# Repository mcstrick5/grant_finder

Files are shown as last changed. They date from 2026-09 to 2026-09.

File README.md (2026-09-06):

# Slide-Out Pan Commode - Manufacturer Brief (Rev A, concept design)

## What it is
A standard folding aluminium bedside commode (1" tube frame, telescoping legs, round 440 mm PP seat/lid, padded backrest, armrests)
fitted with a **side slide-out pan module**. The pan rides on two full-extension ball-bearing drawer
slides mounted under the seat on the existing front and rear cross bars. A caregiver pulls the handle,
the pan slides ~20" (508 mm) out to the side **while the user remains seated**, is lifted straight out
of its carrier by its two end grips, emptied, dropped back in and pushed home where a catch holds it.

## How it works (see Sheet 1 and renders)
1. Two 20" (508 mm) full-extension slides, one clamped under the front cross bar and one under the rear
   cross bar, running side-to-side. Six rubber-lined tube clamps (SP-04) - no welding or drilling of the
   chair frame; the module is a retrofit kit.
2. A carrier plate (SP-01, 400 x 379 mm) is bolted to the moving members of both slides. It has a
   320 mm dia round cutout, concentric with the seat aperture.
3. The round pan (SP-02, 310 mm rim dia) hangs by its 15 mm flange in the cutout, directly under the seat aperture. Its rim top
   sits 22 mm below the seat underside. Pan bottom is 276 mm above the floor - clears the lower side brace.
4. At full extension the pan is entirely outside the leg line (63 mm clearance past the inner face of the
   leg) so it lifts vertically out. A snap-on splash lid (SP-03) is fitted before carrying.
5. Padded backrest (SP-05, 460 x 200 x 45 mm foam/vinyl) straps to the FRONT face of the rear back-bar so a
   user leaning back contacts padding, never the tube.
6. A magnetic catch / spring detent holds the carrier in the closed position; bump stops at full travel.

## Key dimensions
| Item | mm | in |
|---|---|---|
| Overall width / depth | 585 x 455 | 23.0 x 17.9 |
| Seat height (nominal, adjustable) | 470 (420-570) | 18.5 (16.5-22.5) |
| Slide travel | 508 | 20.0 |
| Carrier plate (round cutout 320 dia) | 400 x 379 x 6 | 15.75 x 14.93 x 0.24 |
| Pan rim dia / flange O/A dia / base dia | 310 / 340 / 250 | 12.2 / 13.4 / 9.8 |
| Pan depth | 152 | 6.0 |
| Pan capacity (working / brim) | 6.7 L / 9.3 L | 7 qt / 9.8 qt |
| Design load | 136 kg seated, 15 kg in pan | 300 lb / 33 lb |

## Files
| File | Purpose |
|---|---|
| `commode_slide_pan_closed.step` / `.stl` | Full 3D assembly, pan closed (STEP opens in AutoCAD, SolidWorks, Fusion, FreeCAD) |
| `commode_slide_pan_extended.step` / `.stl` | Full 3D assembly, pan at full extension |
| `part_carrier.step/.stl`, `part_pan.step/.stl`, `part_slides.step/.stl`, `part_backrest.step/.stl` | Individual new parts |
| `sheet1_general_assembly.pdf/.dxf` | GA drawing: front, side, top views, overall dims, notes |
| `sheet2_carrier_plate.pdf/.dxf` | Carrier plate detail + section |
| `sheet3_pan.pdf/.dxf` | Pan detail + section, draft, fill line |
| `sheet4_bracket_bom.pdf/.dxf` | Clamp bracket detail + full Bill of Materials |
| `render_01..06.png` | Shaded renders for quoting / marketing |
| `model.py`, `drawings.py`, `render.py` | Parametric source (CadQuery) - change any dimension and regenerate |

## Questions for the manufacturer / decisions still open
- Material choice for carrier (HDPE vs 304 SS) and pan (moulded PP vs drawn SS) - tooling cost vs volume.
- Handedness: RH shown (slides out to caregiver's right when facing user). Offer LH mirror?
- Slide spec: confirm 100 lb/pair, corrosion-resistant (stainless or zinc + sealed bearings) and washable.
- Whether the base chair is bought-in (retrofit kit) or the manufacturer supplies the whole chair.
- Optional: splash lid that closes automatically as the pan slides out (hinged flap on carrier) - not in Rev A.

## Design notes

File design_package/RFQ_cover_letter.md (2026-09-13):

# REQUEST FOR QUOTE - Rear Slide-Out Pan Bedside Commode (Rev B)

## Date

________________

## Project

Retrofit module for a standard folding aluminium bedside commode that lets a caregiver empty the waste pan
while the user remains seated. The round pan slides 20" (508 mm) straight out the BACK of the chair on two
ball-bearing drawer slides, lifts out for emptying, and slides back to a latched position under the seat.

## Scope of quote

Please quote the following, priced separately:
  A. Prototype: 1 complete working unit (module fitted to a base chair) for fit and function testing.
  B. Pilot run: 10 units.
  C. Production: 100 and 500 units (unit price, tooling, lead time).
For each, state whether you supply the base chair or fit the module to a chair we supply.

## Parts to be made / sourced (see Sheet 4 BOM for full list)
```
  SP-01  Carrier plate 375 x 400 x 6 mm, 320 mm round cutout, side flanges, rear D-handle  (Sheet 2)
  SP-02  Round pan, 310 mm rim / 340 mm flange / 250 mm base, 152 mm deep, 7 qt working  (Sheet 3)
  SP-03  Snap-on splash lid for pan
  SP-04  Tube clamp bracket, 1" saddle with foot, rubber-lined, qty 4  (Sheet 4)
  SP-05  Padded backrest 460 x 200 x 45 mm, mounts in FRONT of the rear bar
  SP-06  Angle rail 40 x 40 x 3 mm x 508 mm, 6061-T6, qty 2  (Sheet 4)
  Bought-in: 2x 20" full-extension slides (100 lb/pair, corrosion resistant), D-handle, magnetic catch,
  bump stops, stainless fasteners.
```

## Key requirements
```
  - Retrofit: clamps to the existing frame, no welding or drilling of the chair.
  - Pan and carrier concentric with the 440 mm round seat; pan must lift freely out of the carrier at full extension.
  - Design load 300 lb (136 kg) seated user; 15 kg in pan at full extension; no tipping with pan extended.
  - Pan, lid and carrier smooth, non-porous, dishwasher/disinfectant safe (PP or 304 SS).
  - Slides and hardware stainless or zinc-plated with sealed bearings; washable.
  - Tolerances per drawings (+/-1.0 mm untoleranced); all edges deburred.
```

## Supplier to confirm / advise
```
  1. Material recommendation for carrier (HDPE vs 304 SS) and pan (moulded PP vs drawn SS) at each volume.
  2. Engineering review of slide/rail loading and tip stability with the pan extended; propose changes if needed.
  3. Whether the design fits your standard commode frame, or dimensions that must change.
  4. Lead time for prototype, pilot and production; tooling costs and ownership; MOQ.
```

## US market / regulatory requirements (product ships to the United States)
```
  - FDA: commode is a Class I medical device (21 CFR 890.3100/890.3110, 510(k)-exempt). Manufacturer must hold
    FDA Establishment Registration and Device Listing and follow 21 CFR 820 QMS (or ISO 13485). Provide evidence.
  - Testing: static load and stability per ISO 17966 (assistive products for personal hygiene) and/or RESNA;
    supply test reports for 300 lb (136 kg) rated user load with pan extended.
  - Materials: skin-contact parts biocompatible (ISO 10993-5/-10); pan/lid plastics food-grade PP. Vinyl, foam and
    plastics to meet California Prop 65 and CPSIA/16 CFR limits for lead, cadmium and phthalates; RoHS declaration.
  - Corrosion: salt-spray / cleaning-agent resistance test on slides, rails, clamps and fasteners (e.g. ASTM B117).
  - Labeling: permanent label with model, rated load, manufacturer, country of origin (19 CFR 134 'Made in China'),
    English instructions for use and cleaning; UDI/labeling per 21 CFR 801 as applicable.
  - Quality: ISO 9001 certificate; pre-shipment inspection (AQL) report; packaging drop test (ISTA/ASTM D4169).
  - Supplier to state the HTS code and confirm any US import tariff applicable to their quote.
```

## Files provided
```
  README_manufacturer_brief.md (start here)  |  sheet1-4 PDF + DXF drawings and BOM
  commode_slide_pan_closed / _extended .STEP + .STL (full assembly)  |  part_*.step (individual parts)
  render_01-06.png (how it works)  |  model.py / drawings.py / render.py (parametric source)
```

## Note

This is a concept design based on standard commode dimensions and has not been physically tested.
Fit to the actual base chair and all structural/safety validation are to be performed by the supplier.

Please reply with your quotation and any design comments. Thank you.

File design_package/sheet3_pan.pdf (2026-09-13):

## TOP VIEW

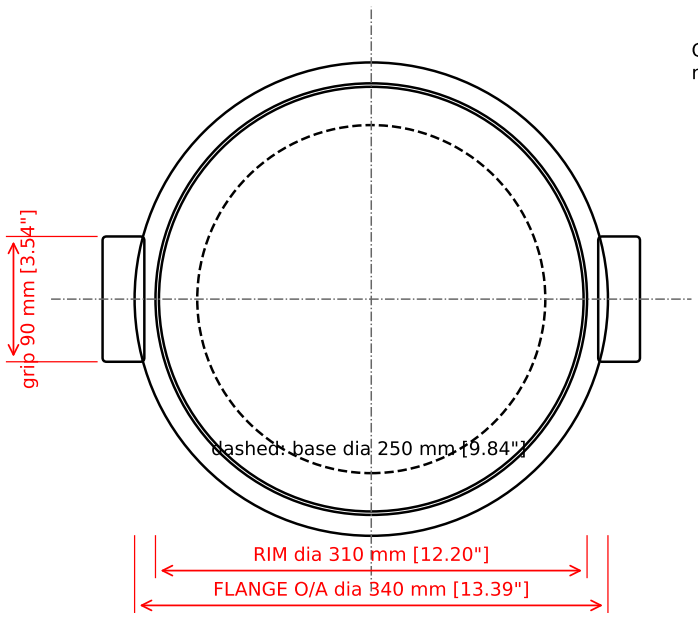
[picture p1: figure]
FLANGE O/A dia 340 mm [13.39"]; RIM dia 310; grip 90 mm [3.54"]; dashed: base dia

Concentric with 440 mm round seat; rim surrounds 300 x 220 seat aperture.

## SECTION B-B (through centre)

MAX FILL line (moulded), 7 qt / 6.7 L

DEPTH 152 mm [6.00"]

BASE dia 250 mm [9.84"]

FLANGE 15 mm [0.59"]

NOTES
0. Round (revolved) pan. Draft angle 11.3 deg. Wall 2.5 mm nominal. Base corner R15 inside.
1. Capacity: ~9.3 L brim-full; 7 qt (6.7 L) working capacity at moulded MAX FILL line 115 mm above base. Concentric with the 440 mm round seat and its 300 x 220 aperture (pan rim 310 dia fully surrounds aperture).
2. Flange rests on carrier plate cutout (Sheet 2). Two moulded end grips for lift-out.
3. Supply with snap-on splash lid (P/N SP-03, same rim profile) - lid fitted once pan is extended before carrying.
4. Material: polypropylene copolymer, min. 2.5 mm wall, autoclavable / dishwasher-safe. Alt: 0.8 mm 304 SS deep-drawn, polished.
5. Tolerance +/-1.0 mm; rim must pass freely through carrier cutout (5 mm radial clearance); flange OD 340 clears carrier side flanges (369 inside).

# SHEET 3 - REMOVABLE ROUND PAN (P/N SP-02) moulded PP or 0.8 mm 304 SS drawn (units mm [in])

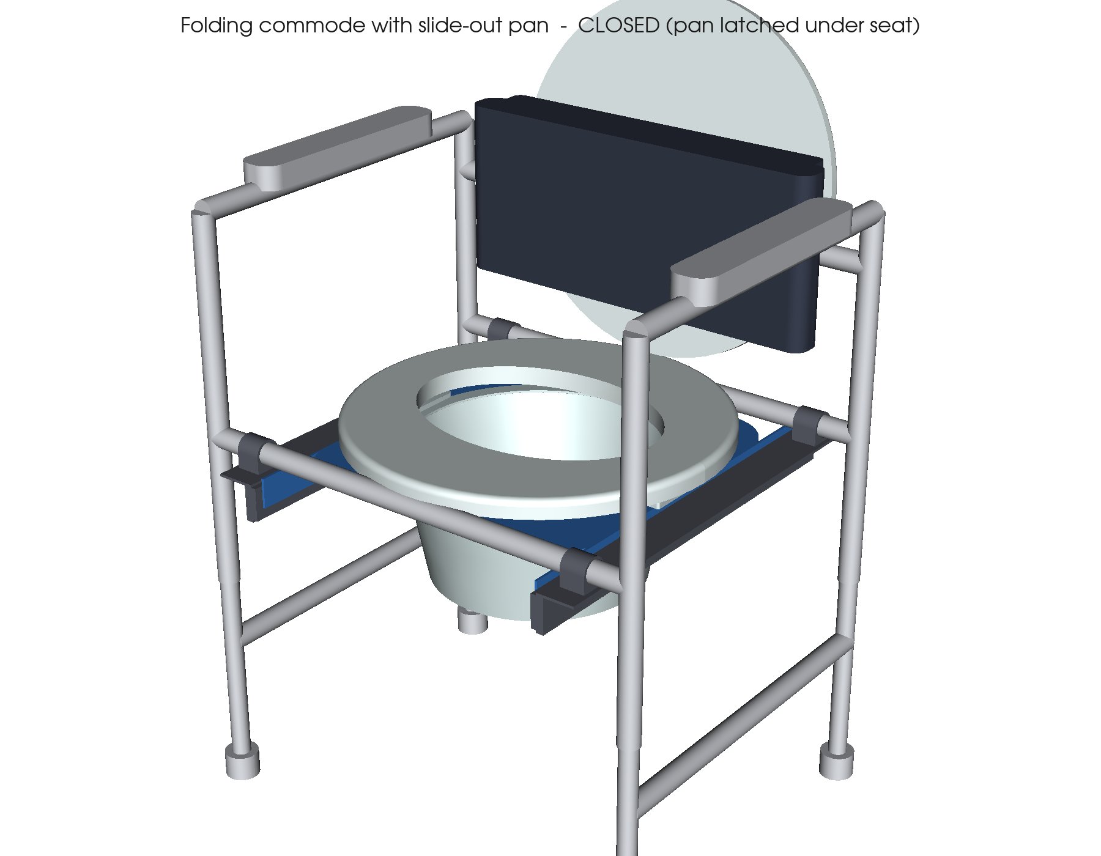
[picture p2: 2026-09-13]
design_package/render_01_closed_iso.png

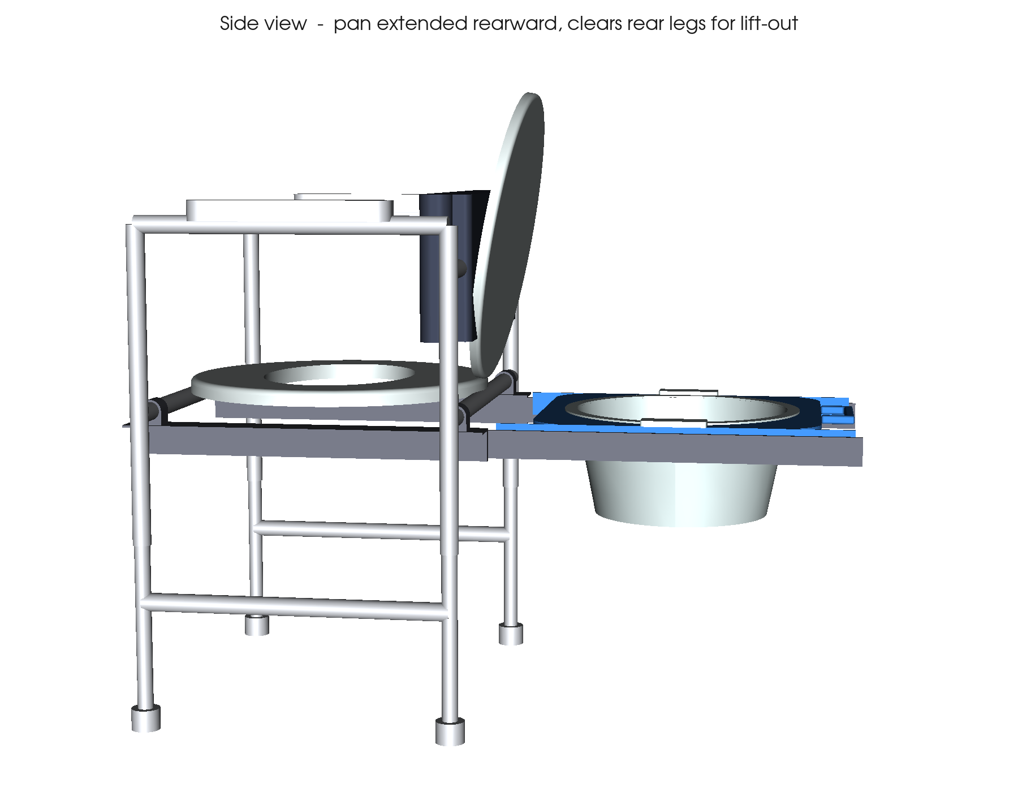
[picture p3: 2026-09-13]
design_package/render_03_extended_side.png

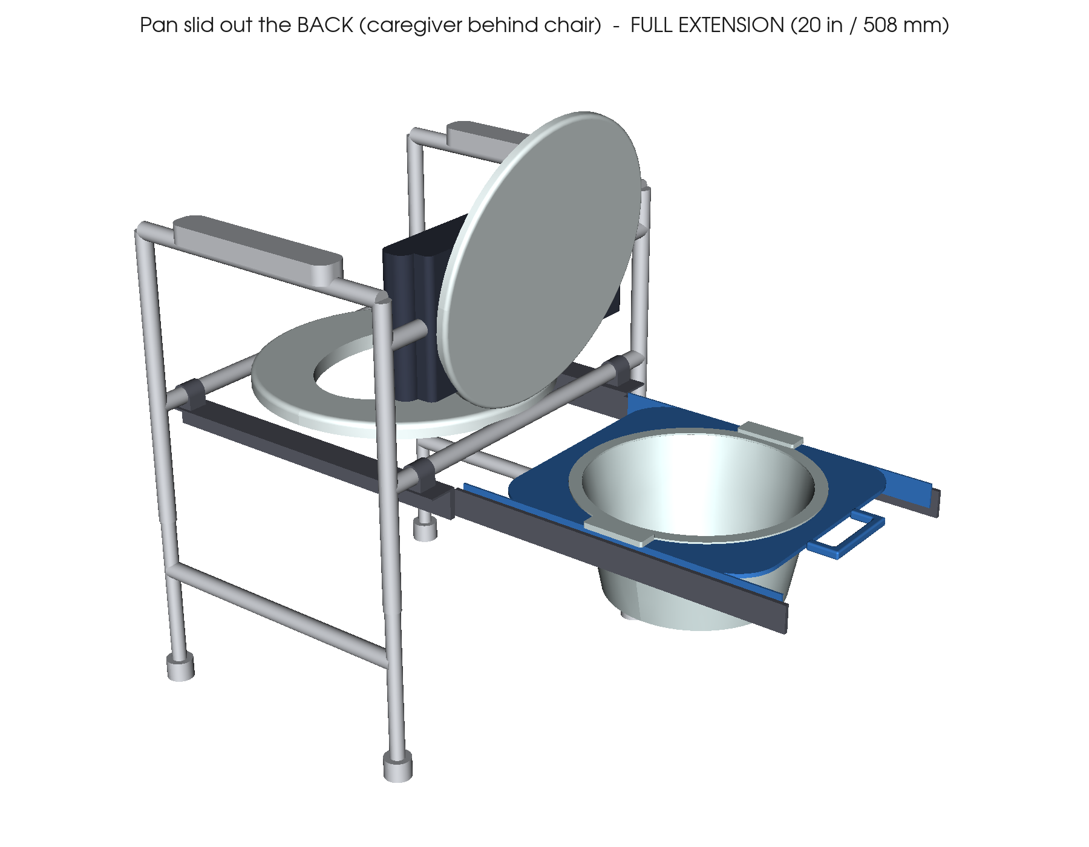
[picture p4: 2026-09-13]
design_package/render_02_extended_iso.png

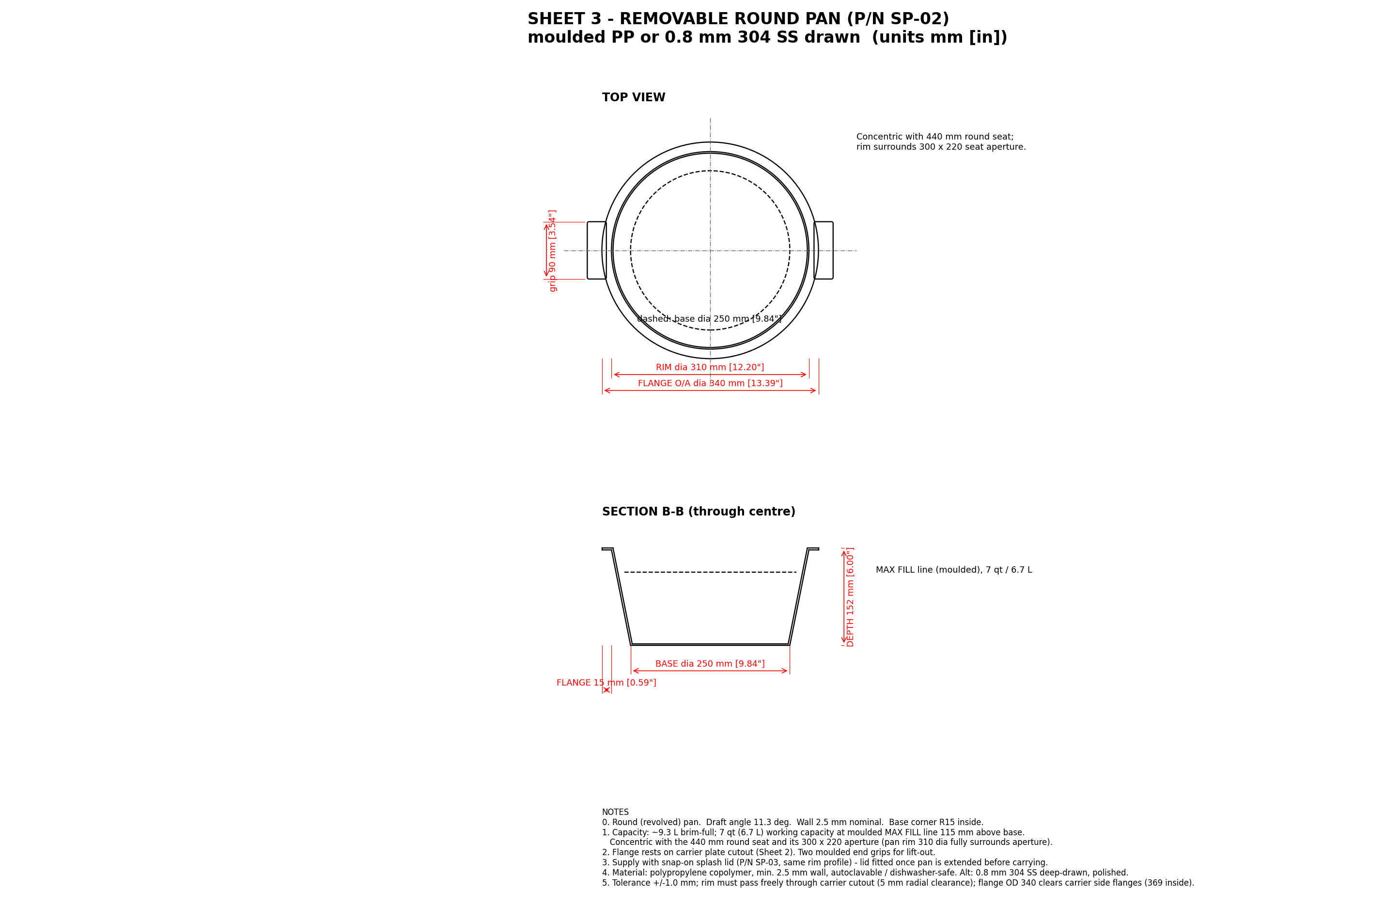
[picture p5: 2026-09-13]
design_package/sheet3_pan.png

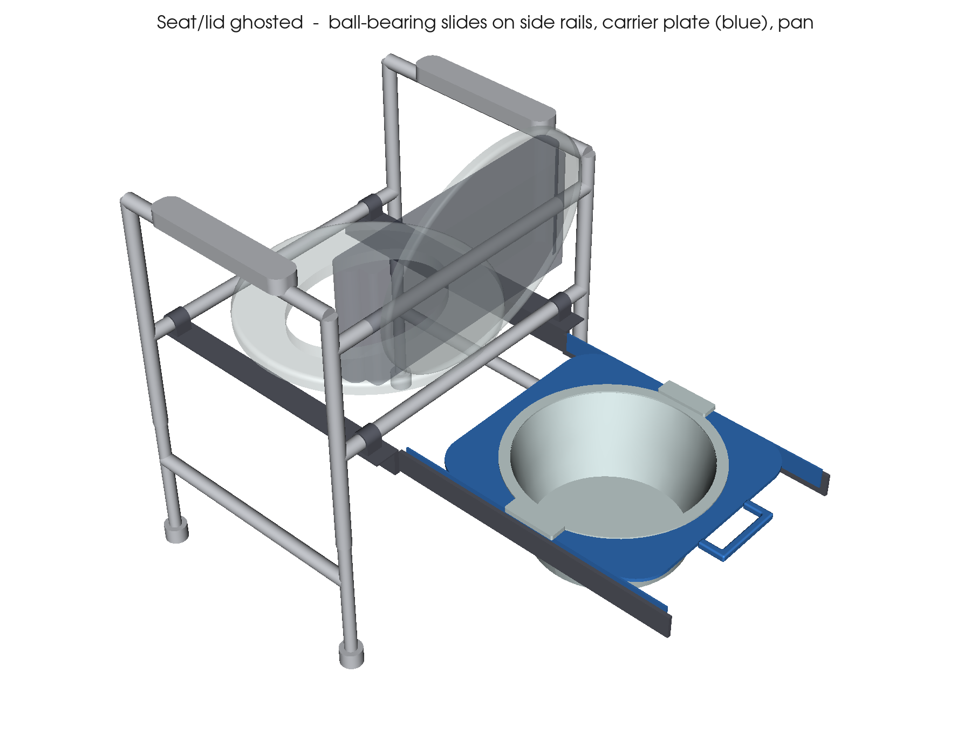
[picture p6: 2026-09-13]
design_package/render_04_extended_seat_ghosted.png

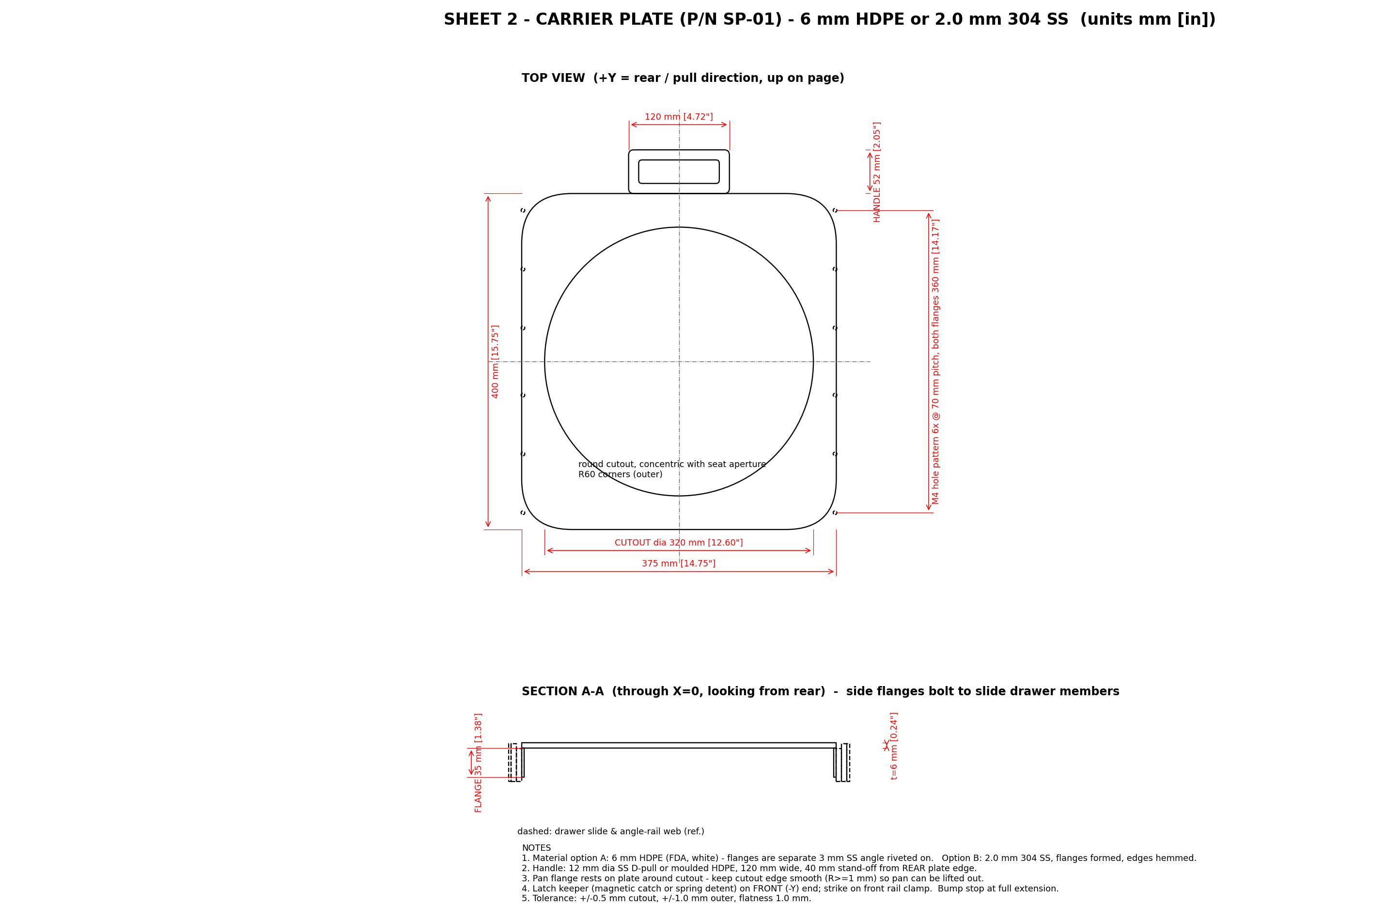
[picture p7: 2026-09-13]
design_package/sheet2_carrier_plate.png

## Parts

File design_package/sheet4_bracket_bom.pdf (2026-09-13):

## CLAMP BRACKET - END VIEW

(2-piece saddle + foot, 30 mm long,

## seen along cross bar)

O/D 31 mm [1.24"]

FOOT 20 mm [0.79"] (bar C/L to rail top) bore 25 mm [1.00"] (1 in tube)

Material: 6061-T6 aluminium or glass-filled nylon. 2x M5 clamp screws (split line), 2x M4 screws down into angle-rail top leg. Rubber liner 1 mm inside bore
to protect powder-coat & prevent slip.
Qty 4 (front & rear cross bar, at X = +/-220 mm).
RAIL SP-06: 40x40x3 6061-T6 angle, 508 mm long, web faces inboard; slide cabinet member bolts to web (4x M4), qty 2.
ITEM | P/N | DESCRIPTION | MATERIAL | QTY
1 | BASE | Folding commode chair, 1" alu frame, seat, lid, arms (existing / purchased) | Aluminium / PP | 1
2 | SLD-20 | Full-extension ball-bearing drawer slide, 20" (508 mm), 45 mm, 100 lb/pair, detent | Zinc-plated or SS | 2
3 | SP-01 | Carrier plate with formed flanges & cutout (Sheet 2) | 6 mm HDPE or 2 mm 304 SS | 1
4 | SP-02 | Removable pan, flanged rim, end grips (Sheet 3) | PP copolymer / 304 SS | 1
5 | SP-03 | Snap-on splash lid for SP-02 | PP copolymer | 1
6 | SP-04 | Tube clamp bracket, 1" saddle with foot (this sheet) | 6061-T6 or GF nylon | 4
6a | SP-06 | Angle rail 40x40x3 x 508 mm, drilled for slide + 2 clamps (this sheet) | 6061-T6 aluminium | 2
7 | HDL-120 | D-pull handle 120 mm, 12 mm dia | 304 SS | 1
8 | LTCH | Magnetic catch 5 kg (or spring ball detent) + strike | SS / nylon | 1
9 | HW | M4x10 SS button-head screws + nyloc (slide to carrier flange) | A2 SS | 12
10 | HW | M5x20 SS screws + nyloc (clamp halves) | A2 SS | 8
11 | HW | M4x8 SS screws (clamp foot to rail; slide cabinet member to rail web) | A2 SS | 16
12 | STOP | Rubber bump stop 15 mm (full-extension stop on slide) | EPDM | 2
13 | SP-05 | Backrest pad 460x200x45, wraps FRONT of back-bar, rear shell w/ 2 hook-&-loop straps | PU foam / vinyl, PP shell | 1

## BILL OF MATERIALS - slide-out pan module

GENERAL
- Dimensions in mm [inches]. Untoleranced +/-1.0 mm. Break all edges 0.5 mm.
- Frame contact parts must not damage powder-coat: use rubber-lined clamps.
- Slide rails to be mounted parallel within 0.5 mm over 508 mm; check free travel with 20 kg in pan.
- Design load: 136 kg (300 lb) seated user on base chair; 15 kg in pan on slides at full extension.
- Finish: pan & carrier smooth, non-porous, cleanable with hospital disinfectants.
- Pan extends to the REAR of the chair (caregiver behind user); no left/right handedness.

# SHEET 4 - TUBE CLAMP BRACKET (P/N SP-04) & BILL OF MATERIALS (units mm [in])

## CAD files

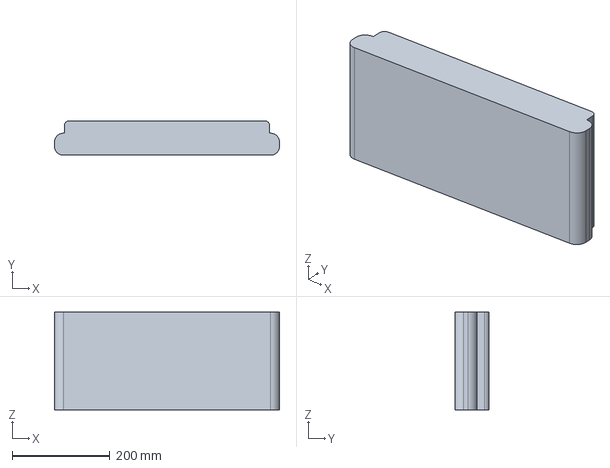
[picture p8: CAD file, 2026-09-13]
design_package/part_backrest.step
460.0 x 70.4 x 200.0 mm

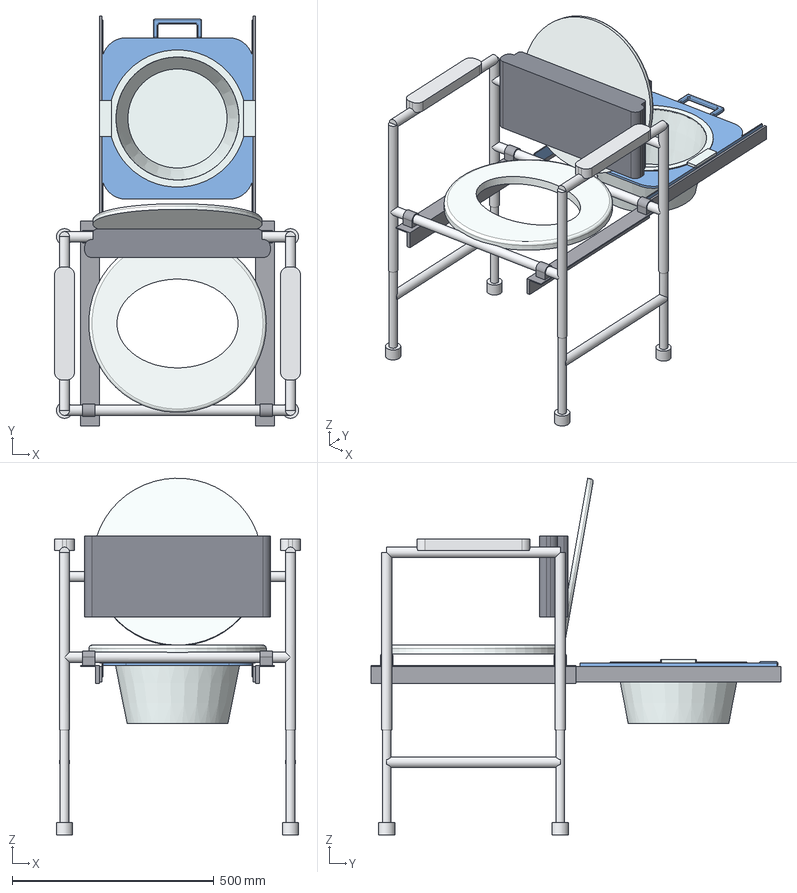
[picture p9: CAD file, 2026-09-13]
design_package/commode_slide_pan_extended.step
610.0 x 1016.0 x 883.5 mm
frame
seat
lid
backrest
slides
carrier
pan

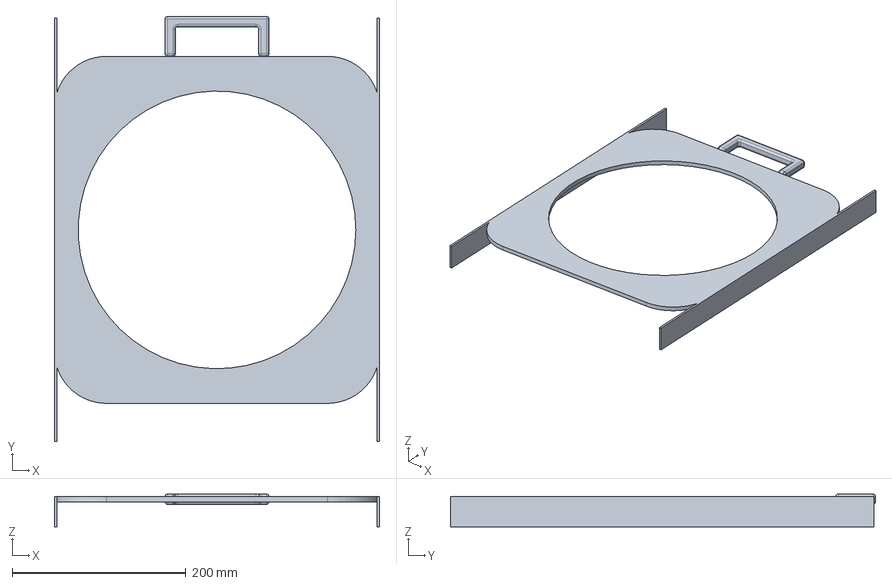
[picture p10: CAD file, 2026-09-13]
design_package/part_carrier.step
374.6 x 490.0 x 38.0 mm

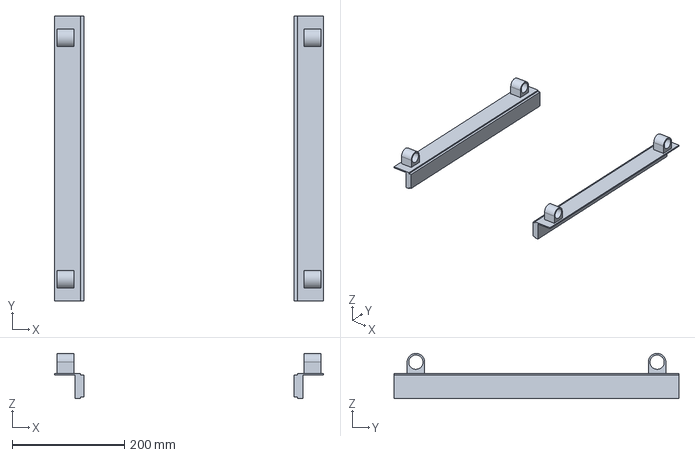
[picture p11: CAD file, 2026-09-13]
design_package/part_slides.step
480.0 x 508.0 x 80.7 mm

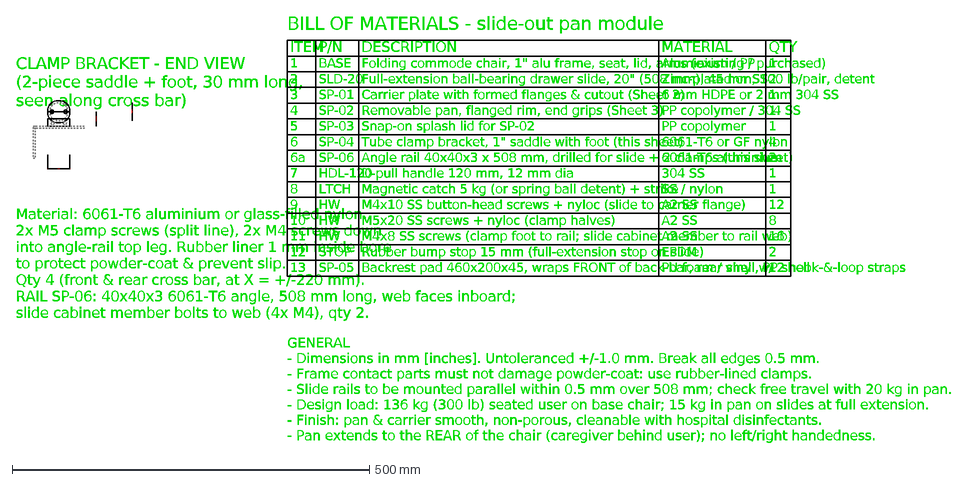
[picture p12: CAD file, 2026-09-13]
design_package/sheet4_bracket_bom.dxf
CLAMP BRACKET - END VIEW
(2-piece saddle + foot, 30 mm long,
seen along cross bar)
O/D 31 mm [1.24"]
FOOT 20 mm [0.79"] (bar C/L to rail top)
bore 25 mm [1.00"] (1 in tube)
Material: 6061-T6 aluminium or glass-filled nylon.
2x M5 clamp screws (split line), 2x M4 screws down
into angle-rail top leg. Rubber liner 1 mm inside bore
to protect powder-coat & prevent slip.
Qty 4 (front & rear cross bar, at X = +/-220 mm).
RAIL SP-06: 40x40x3 6061-T6 angle, 508 mm long, web faces inboard;
slide cabinet member bolts to web (4x M4), qty 2.
ITEM
P/N
DESCRIPTION
MATERIAL
QTY
1
BASE
Folding commode chair, 1" alu frame, seat, lid, arms (existing / purchased)
Aluminium / PP
2
SLD-20
Full-extension ball-bearing drawer slide, 20" (508 mm), 45 mm, 100 lb/pair, detent
Zinc-plated or SS
3
SP-01
Carrier plate with formed flanges & cutout (Sheet 2)
6 mm HDPE or 2 mm 304 SS
4
SP-02
Removable pan, flanged rim, end grips (Sheet 3)
PP copolymer / 304 SS
5
SP-03
Snap-on splash lid for SP-02
PP copolymer
6
SP-04
Tube clamp bracket, 1" saddle with foot (this sheet)
6061-T6 or GF nylon
6a
SP-06
Angle rail 40x40x3 x 508 mm, drilled for slide + 2 clamps (this sheet)
6061-T6 aluminium
7
HDL-120
D-pull handle 120 mm, 12 mm dia
304 SS
8
LTCH
Magnetic catch 5 kg (or spring ball detent) + strike
SS / nylon
9
HW
M4x10 SS button-head screws + nyloc (slide to carrier flange)
A2 SS
12
10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

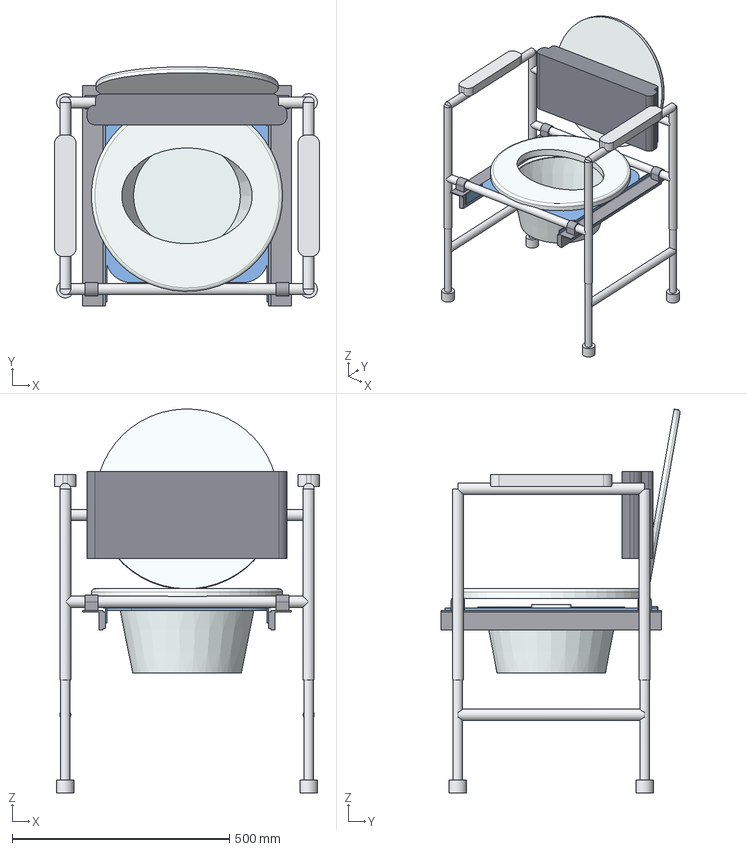
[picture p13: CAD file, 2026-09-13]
design_package/commode_slide_pan_closed.step
610.0 x 550.7 x 883.5 mm
frame
seat
lid
backrest
slides
carrier
pan

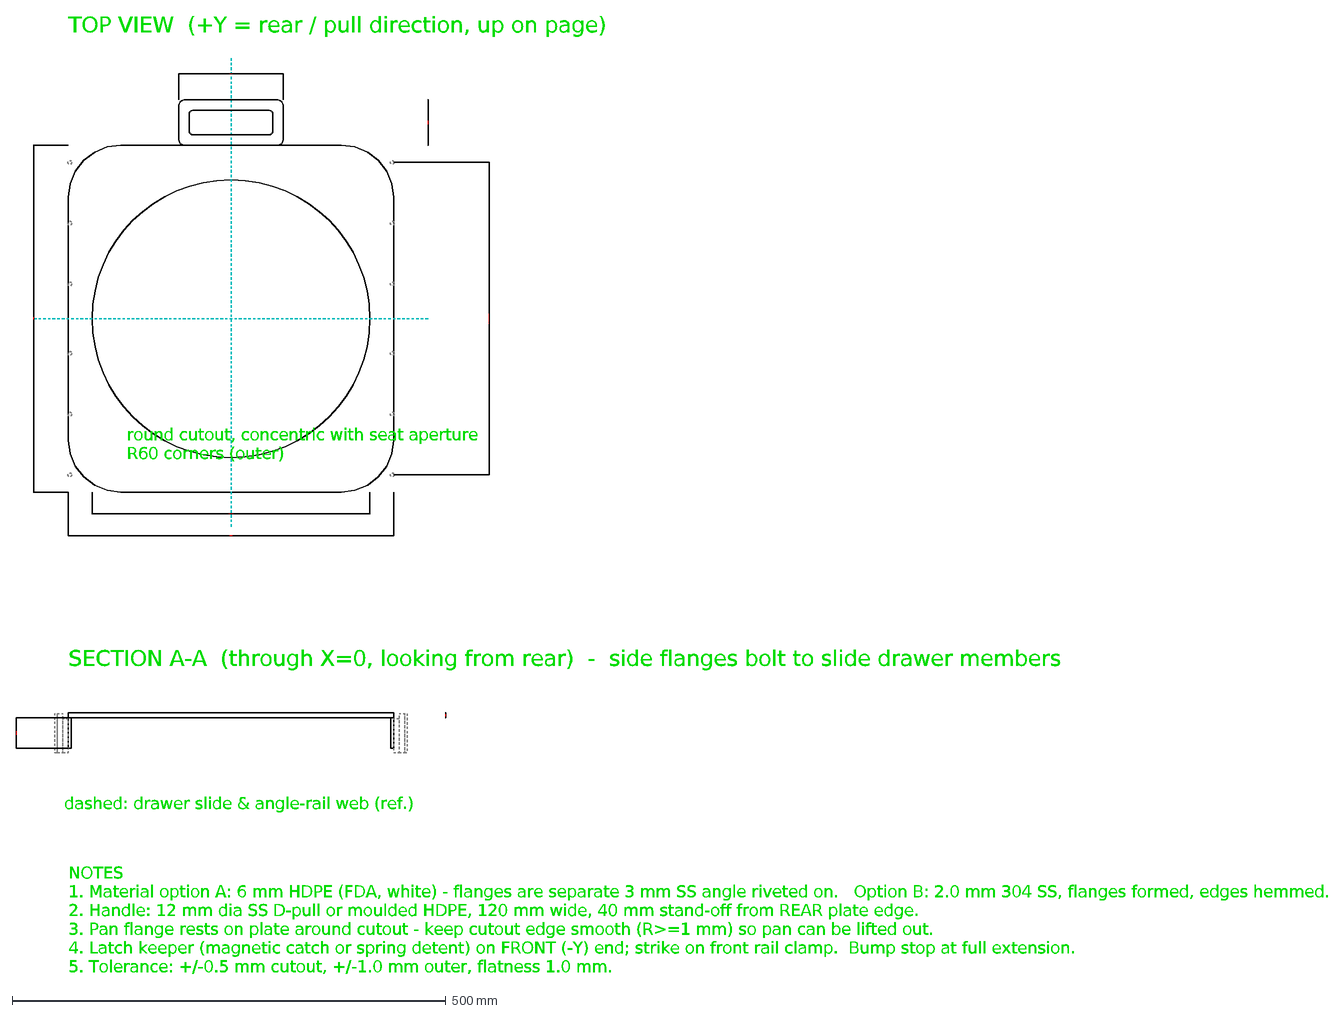
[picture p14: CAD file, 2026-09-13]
design_package/sheet2_carrier_plate.dxf
TOP VIEW (+Y = rear / pull direction, up on page)
375 mm [14.75"]
CUTOUT dia 320 mm [12.60"]
400 mm [15.75"]
HANDLE 52 mm [2.05"]
120 mm [4.72"]
M4 hole pattern 6x @ 70 mm pitch, both flanges 360 mm [14.17"]
round cutout, concentric with seat aperture
R60 corners (outer)
SECTION A-A (through X=0, looking from rear) - side flanges bolt to slide drawer members
FLANGE 35 mm [1.38"]
t=6 mm [0.24"]
dashed: drawer slide & angle-rail web (ref.)
NOTES
1. Material option A: 6 mm HDPE (FDA, white) - flanges are separate 3 mm SS angle riveted on. Option B: 2.0 mm 304 SS, flanges formed, edges hemmed.
2. Handle: 12 mm dia SS D-pull or moulded HDPE, 120 mm wide, 40 mm stand-off from REAR plate edge.
3. Pan flange rests on plate around cutout - keep cutout edge smooth (R>=1 mm) so pan can be lifted out.
4. Latch keeper (magnetic catch or spring detent) on FRONT (-Y) end; strike on front rail clamp. Bump stop at full extension.
5. Tolerance: +/-0.5 mm cutout, +/-1.0 mm outer, flatness 1.0 mm.

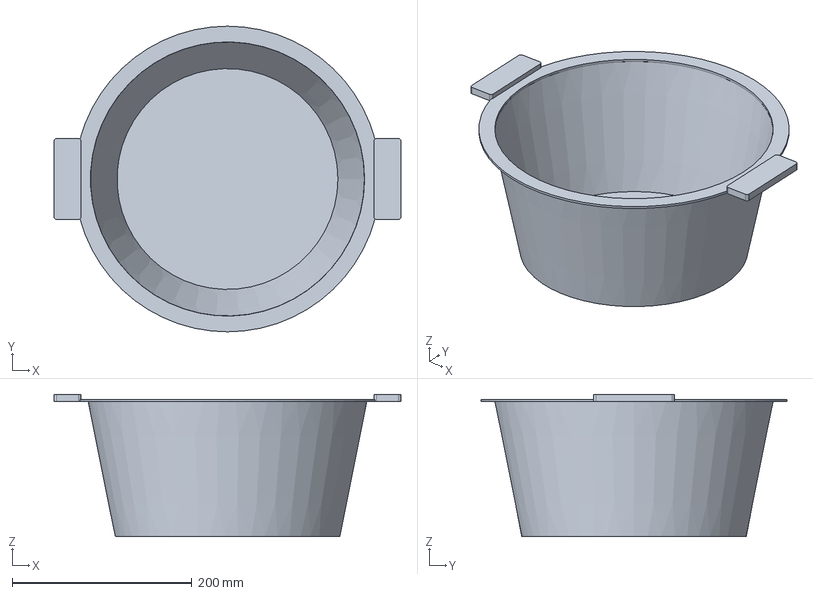
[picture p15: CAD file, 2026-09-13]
design_package/part_pan.step
386.0 x 340.0 x 158.0 mm

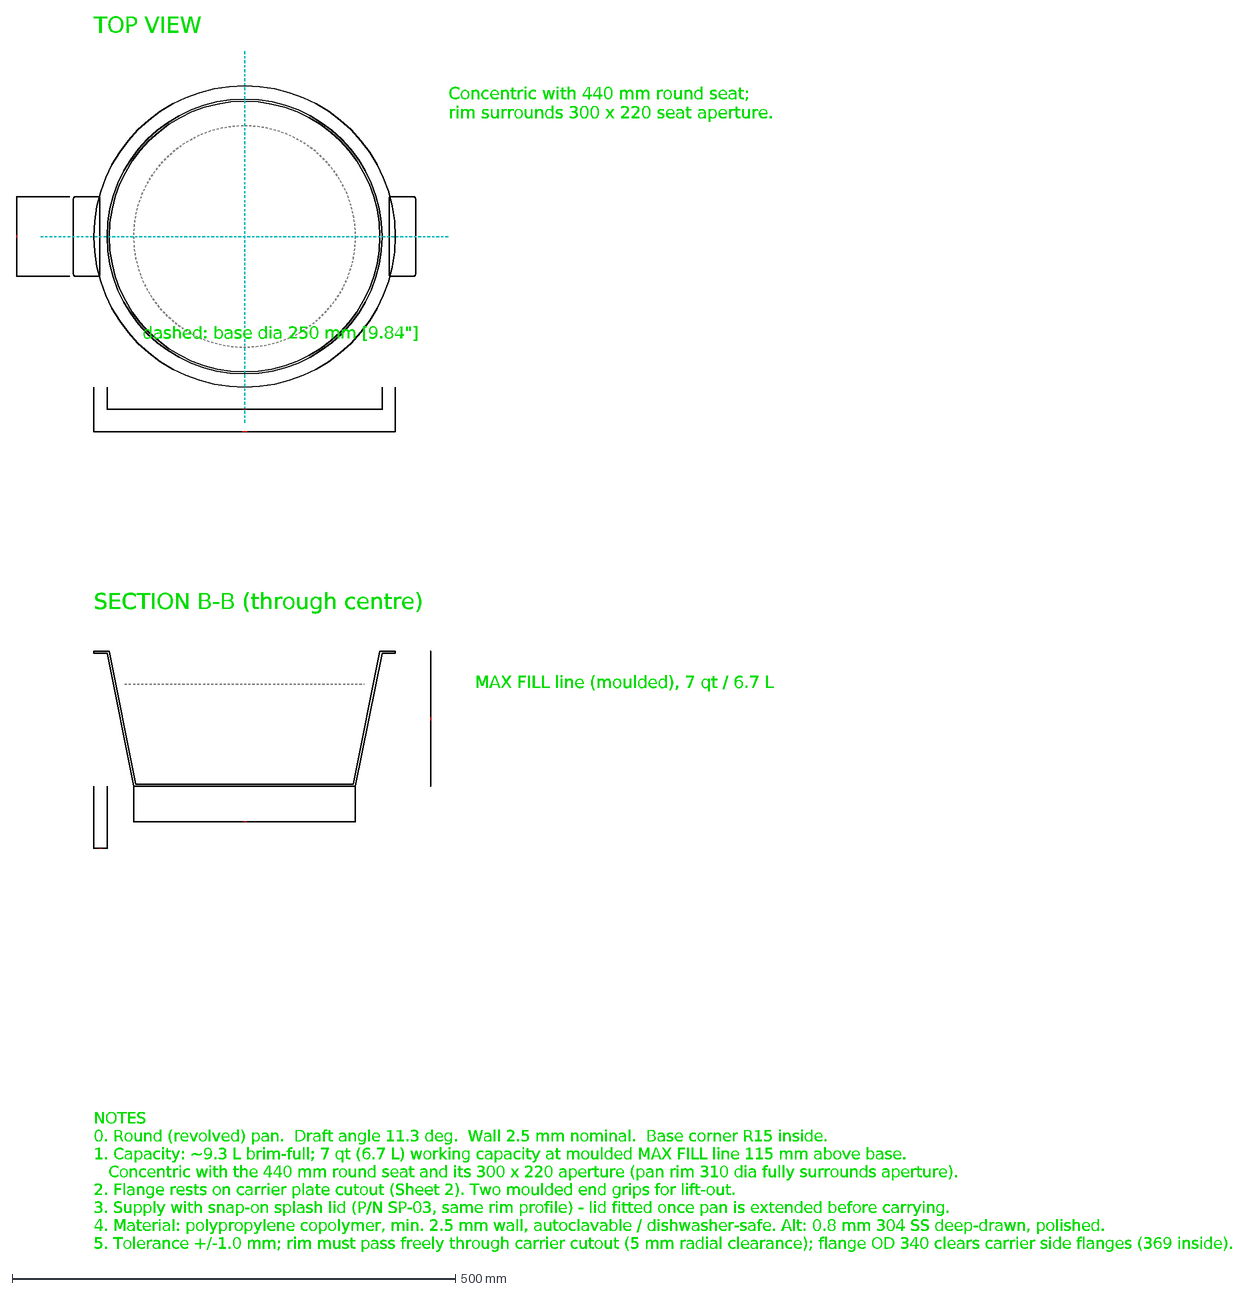
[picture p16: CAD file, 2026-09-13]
design_package/sheet3_pan.dxf
TOP VIEW
Concentric with 440 mm round seat;
rim surrounds 300 x 220 seat aperture.
FLANGE O/A dia 340 mm [13.39"]
RIM dia 310 mm [12.20"]
grip 90 mm [3.54"]
dashed: base dia 250 mm [9.84"]
SECTION B-B (through centre)
MAX FILL line (moulded), 7 qt / 6.7 L
DEPTH 152 mm [6.00"]
BASE dia 250 mm [9.84"]
FLANGE 15 mm [0.59"]
NOTES
0. Round (revolved) pan. Draft angle 11.3 deg. Wall 2.5 mm nominal. Base corner R15 inside.
1. Capacity: ~9.3 L brim-full; 7 qt (6.7 L) working capacity at moulded MAX FILL line 115 mm above base.
Concentric with the 440 mm round seat and its 300 x 220 aperture (pan rim 310 dia fully surrounds aperture).
2. Flange rests on carrier plate cutout (Sheet 2). Two moulded end grips for lift-out.
3. Supply with snap-on splash lid (P/N SP-03, same rim profile) - lid fitted once pan is extended before carrying.
4. Material: polypropylene copolymer, min. 2.5 mm wall, autoclavable / dishwasher-safe. Alt: 0.8 mm 304 SS deep-drawn, polished.
5. Tolerance +/-1.0 mm; rim must pass freely through carrier cutout (5 mm radial clearance); flange OD 340 clears carrier side flanges (369 inside).

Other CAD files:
design_package/sheet1_general_assembly.dxf
design_package/commode_slide_pan_closed.stl
design_package/commode_slide_pan_extended.stl
design_package/part_backrest.stl
design_package/part_carrier.stl
design_package/part_pan.stl
design_package/part_slides.stl

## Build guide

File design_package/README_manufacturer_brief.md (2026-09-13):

# Slide-Out Pan Commode - Manufacturer Brief (Rev B, concept design - REAR slide-out)

## What it is
A standard folding aluminium bedside commode (1" tube frame, telescoping legs, round 440 mm PP seat/lid, padded backrest, armrests)
fitted with a **rear slide-out pan module**. The pan rides on two full-extension ball-bearing drawer
slides that run front-to-back under the seat, on angle rails clamped to the existing front and rear cross bars.
A caregiver standing **behind the chair** pulls the handle, the pan slides ~20" (508 mm) out the back
**while the user remains seated**, is lifted straight out
of its carrier by its two end grips, emptied, dropped back in and pushed home where a catch holds it.

## How it works (see Sheet 1 and renders)
1. Two 40x40x3 mm aluminium angle rails (SP-06, 508 mm long) run front-to-back under the seat at
   +/-200 mm from centre, each held by a rubber-lined tube clamp (SP-04) on the front and rear cross bar -
   four clamps total, no welding or drilling of the chair frame; the module is a retrofit kit.
2. A 20" (508 mm) full-extension slide bolts to the web of each rail. A carrier plate (SP-01, 375 mm wide x
   400 mm long) with down-turned side flanges is bolted to the moving members of both slides. It has a
   320 mm dia round cutout, concentric with the seat aperture, and a D-pull handle on its rear edge.
3. The round pan (SP-02, 310 mm rim dia) hangs by its 15 mm flange in the cutout, directly under the seat aperture. Its rim top
   sits 22 mm below the seat underside. Pan bottom is 276 mm above the floor - clears the lower side brace.
4. At full extension the pan is entirely behind the rear legs (110 mm clearance past the rear leg) so it
   lifts vertically out. The rear cross bar sits above the rails and the backrest pad is above the pan path,
   so nothing obstructs travel. A snap-on splash lid (SP-03) is fitted before carrying.
5. Padded backrest (SP-05, 460 x 200 x 45 mm foam/vinyl) straps to the FRONT face of the rear back-bar so a
   user leaning back contacts padding, never the tube.
6. A magnetic catch / spring detent holds the carrier in the closed position; bump stops at full travel.

## Key dimensions
| Item | mm | in |
|---|---|---|
| Overall width / depth | 585 x 455 | 23.0 x 17.9 |
| Seat height (nominal, adjustable) | 470 (420-570) | 18.5 (16.5-22.5) |
| Slide travel | 508 | 20.0 |
| Carrier plate, W x L (round cutout 320 dia) | 375 x 400 x 6 | 14.75 x 15.75 x 0.24 |
| Angle rails (2), 40x40x3, centre spacing | 508 long, 400 c/c | 20.0 long, 15.75 c/c |
| Pan overhang behind rear leg at full extension | 450 | 17.7 |
| Pan rim dia / flange O/A dia / base dia | 310 / 340 / 250 | 12.2 / 13.4 / 9.8 |
| Pan depth | 152 | 6.0 |
| Pan capacity (working / brim) | 6.7 L / 9.3 L | 7 qt / 9.8 qt |
| Design load | 136 kg seated, 15 kg in pan | 300 lb / 33 lb |

## Files
| File | Purpose |
|---|---|
| `commode_slide_pan_closed.step` / `.stl` | Full 3D assembly, pan closed (STEP opens in AutoCAD, SolidWorks, Fusion, FreeCAD) |
| `commode_slide_pan_extended.step` / `.stl` | Full 3D assembly, pan at full extension |
| `part_carrier.step/.stl`, `part_pan.step/.stl`, `part_slides.step/.stl`, `part_backrest.step/.stl` | Individual new parts |
| `sheet1_general_assembly.pdf/.dxf` | GA drawing: front, side, top views, overall dims, notes |
| `sheet2_carrier_plate.pdf/.dxf` | Carrier plate detail + section |
| `sheet3_pan.pdf/.dxf` | Pan detail + section, draft, fill line |
| `sheet4_bracket_bom.pdf/.dxf` | Clamp bracket detail + full Bill of Materials |
| `render_01..06.png` | Shaded renders for quoting / marketing |
| `model.py`, `drawings.py`, `render.py` | Parametric source (CadQuery) - change any dimension and regenerate |

## Questions for the manufacturer / decisions still open
- Material choice for carrier (HDPE vs 304 SS) and pan (moulded PP vs drawn SS) - tooling cost vs volume.
- Pan exits to the REAR (caregiver behind user) - no left/right handedness. Confirm the caregiver has
  ~18" of clear floor space behind the chair in the intended use setting (e.g. not pushed against a wall).
- Slide spec: confirm 100 lb/pair, corrosion-resistant (stainless or zinc + sealed bearings) and washable.
- Whether the base chair is bought-in (retrofit kit) or the manufacturer supplies the whole chair.
- Optional: splash lid that closes automatically as the pan slides out (hinged flap on carrier) - not in Rev A.

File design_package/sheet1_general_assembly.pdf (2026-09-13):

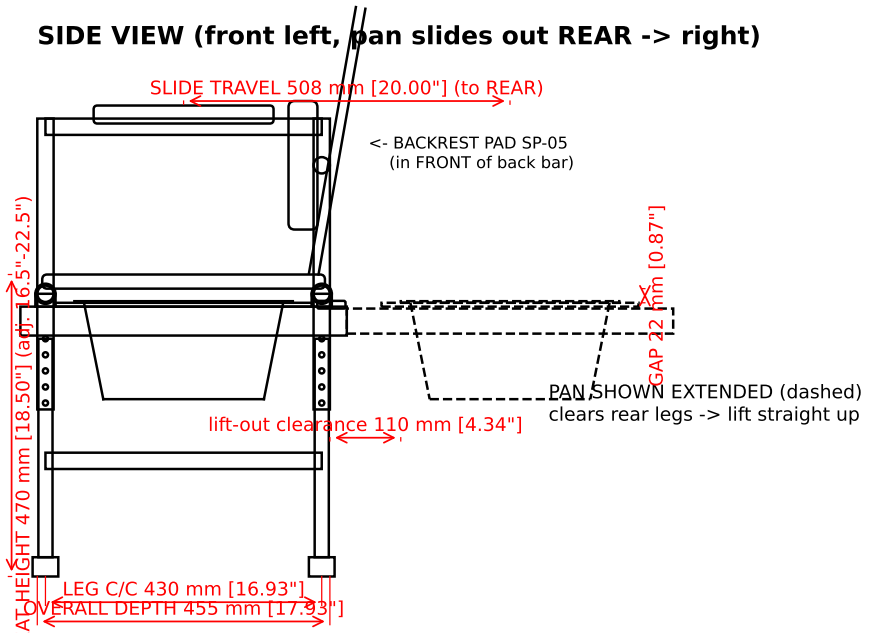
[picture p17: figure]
<- BACKREST PAD SP-05 (in FRONT of back bar); PAN SHOWN EXTENDED (dashed) clears rear legs -> lift straight up; OVERALL DEPTH 455 mm [17.93"]; LEG C/C 430 mm [16.93"]; SLIDE TRAVEL 508 mm [20.00"] (to REAR); lift-out clearance 110 mm [4.34"]; GAP 22 mm [0.87"]

## SIDE VIEW (front left, pan slides out REAR -> right)

SEAT HEIGHT 470 mm [18.50"] (adj. 16.5"-22.5")

PAN CLEARANCE TO FLOOR 276 mm [10.87"]
SLIDE UNDERSIDE 375 mm [14.76"]

## FRONT VIEW (slides on side rails, section through pan)

OVERALL WIDTH 585 mm [23.05"]

LEG C/C 560 mm [22.05"]

RAIL C/C 400 mm [15.75"]

CARRIER WIDTH 375 mm [14.75"]

CROSS BAR C/L 440 mm [17.32"]

OVERALL HEIGHT 733 mm [28.86"]

## TOP VIEW (seat & lid removed) - pan closed, extended (rear) position dashed

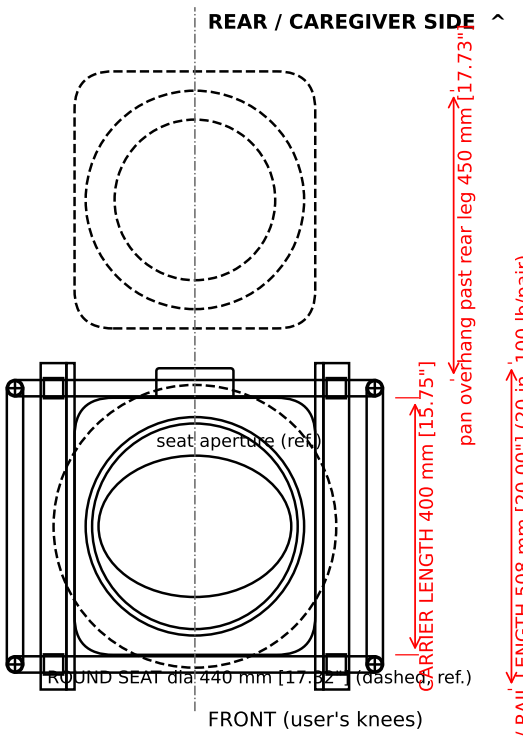
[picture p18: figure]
seat; aperture (ref.); ROUND SEAT dia; 440 mm [17.32"] (dashed, ref.); REAR / CAREGIVER SIDE ^; FRONT (user's knees); CARRIER LENGTH 400 mm [15.75"]

SLIDE / RAIL LENGTH 508 mm [20.00"] (20 in, 100 lb/pair) pan overhang past rear leg 450 mm [17.73"]

lift-out clearance 110 mm [4.34"]

NOTES
1. Base chair: standard folding aluminium commode, 1" (25.4 mm) x 1.5 mm wall tube, telescoping legs, 5-position height adjust.
2. Slide-out pan module: two 40x40x3 aluminium angle rails (P/N SP-06) run front-to-back under the seat and clamp to the existing front & rear cross bars with 4x tube clamps (2 per rail) - no welding, retrofit-able.
3. Two 20" full-extension ball-bearing drawer slides, 45 mm x 12.7 mm, stainless or zinc-plated, min. 100 lb (45 kg) rated
per pair, with soft-close/detent, bolted to the rail webs.
4. Carrier plate (blue) rides on slides; pan hangs by its rim in the round cutout and lifts straight out when extended.
5. Pan slides out to the REAR of the seated user - caregiver stands behind the chair. Backrest pad (SP-05) and back bar are above the pan path; rear cross bar sits above the rails so nothing obstructs travel.
6. Spring latch / magnetic catch holds carrier in CLOSED position; positive stop at full extension.
7. All edges deburred. Static load: 300 lb (136 kg) user. Materials in Sheet 4 BOM.

SHEET 1 - GENERAL ASSEMBLY: Folding commode with REAR slide-out pan (units mm [in], scale 1:1 in DXF)

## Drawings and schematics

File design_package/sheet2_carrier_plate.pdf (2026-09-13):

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

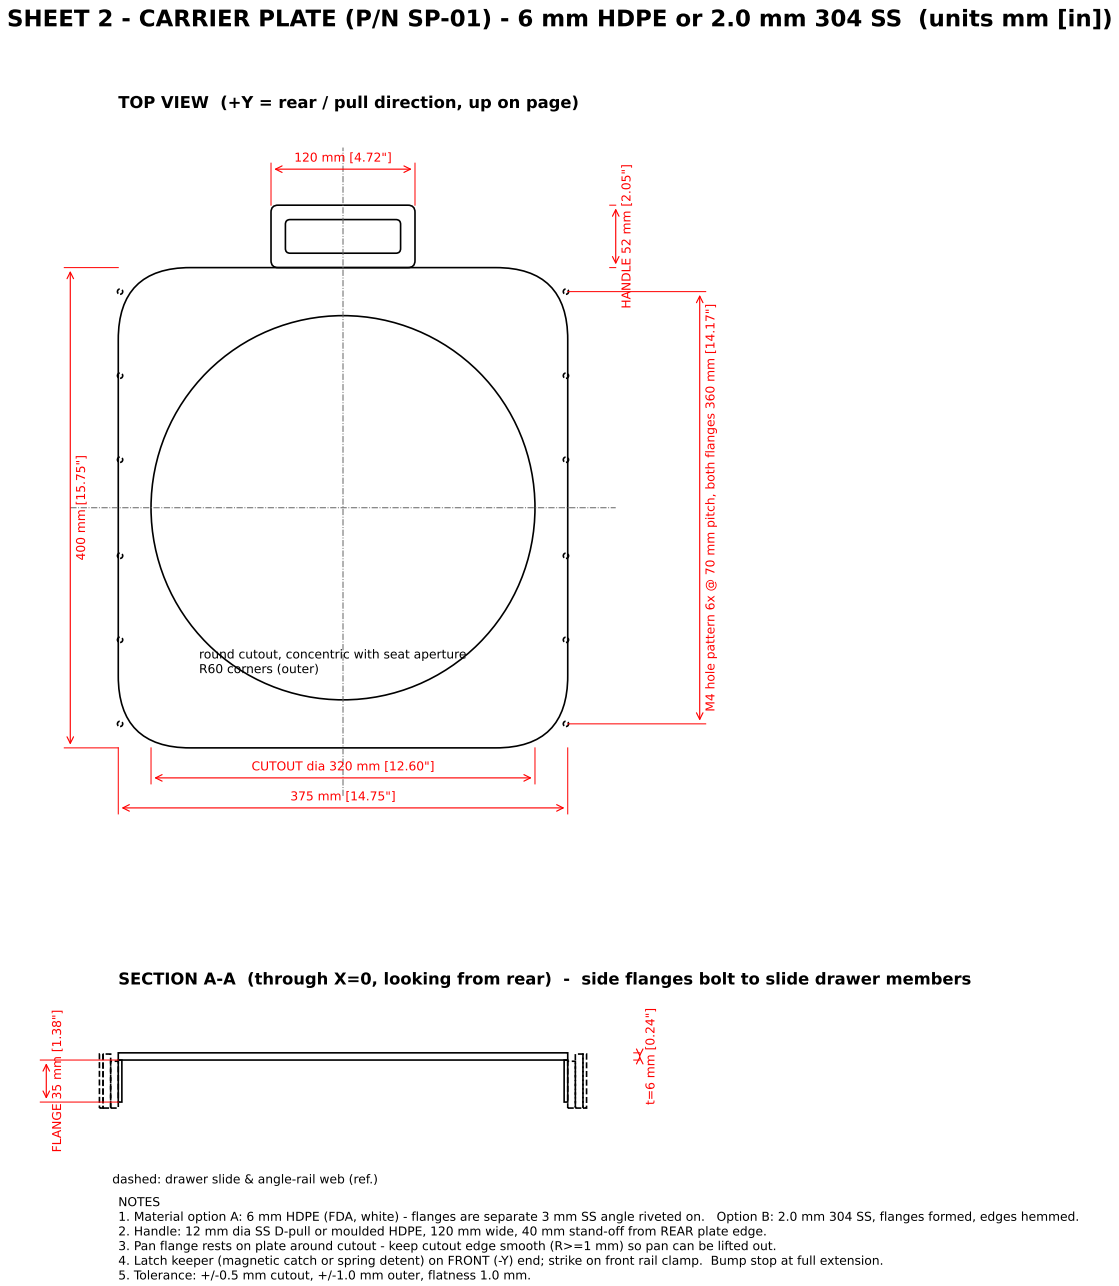
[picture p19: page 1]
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

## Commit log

2026-09-06 Slide-out pan commode design package (CAD, drawings, renders, BOM)
    [commode_slide_pan_closed.step, commode_slide_pan_closed.stl, commode_slide_pan_extended.step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]
2026-09-13 Rev B: pan slides out the REAR (caregiver behind chair); rails clamped to front/rear cross bars
    [commode_slide_pan_closed.step, commode_slide_pan_closed.stl, commode_slide_pan_extended.step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]
2026-09-13 RFQ: drop From, add US regulatory requirements
